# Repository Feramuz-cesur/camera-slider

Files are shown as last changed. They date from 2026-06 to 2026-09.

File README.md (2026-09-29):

# Camera Slider

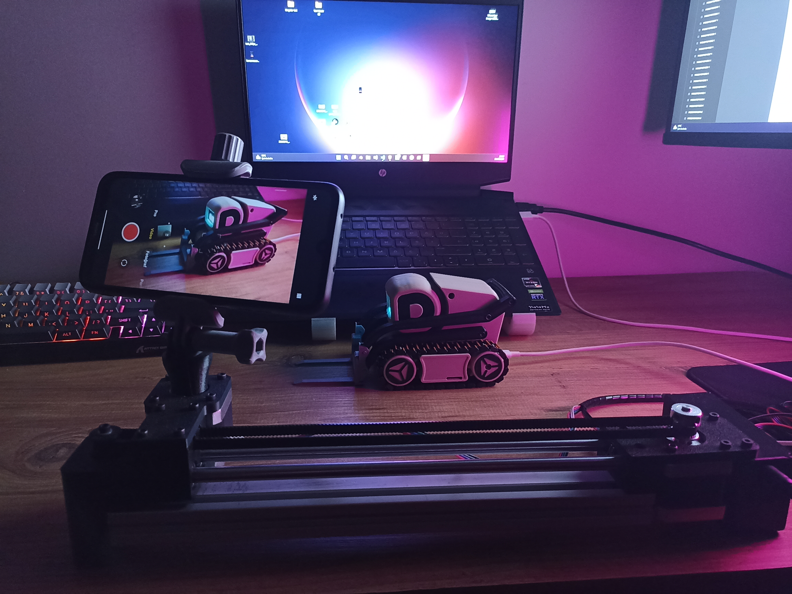
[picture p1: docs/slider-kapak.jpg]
Camera Slider: telefonla çekim yaparken


ESP32-C3 tabanlı, WiFi üzerinden kontrol edilen 2 eksenli motorlu kamera slider'ı.
Lineer eksen kamerayı GT2 kayışlı bir ray üzerinde taşır, rotary (pan) eksen ise
ray üzerindeki platformu 360° döndürür. Tüm kontrol telefon/bilgisayar
tarayıcısından çalışan web arayüzüyle yapılır — uygulama kurmak gerekmez.

## Özellikler

- **2 eksen:** lineer slider (NEMA 17 + GT2 kayış) ve 360° pan platformu (NEMA 17 direkt tahrik)
- **Web arayüzü:** cihaz üzerindeki LittleFS'ten sunulur; canlı durum ve kontrol WebSocket üzerinden
- **WiFi:** ev ağına bağlanır (`camera-slider.local`), bağlanamazsa kendi hotspot'unu açar
  (SSID `CameraSlider`, captive portal ile kurulum sayfası otomatik açılır)
- **Otomatik hareket:** başlangıç/bitiş noktaları arasında ayarlanabilir hızda gidiş-geliş,
  iki eksen ortak saat üzerinden senkron çalışır
- **Homing:** limit switch ile lineer eksen sıfırlama (hızlı yaklaş → geri çekil → yavaş tekrar yaklaş)
- **Jog:** web arayüzünden elle sürme, hız ayarlanabilir
- **OLED:** kart üzerindeki 0.42" ekranda IP adresi; açılışta Wi-Fi deneme sayacı,
  hotspot modunda ağ adı ve şifre
- Adım üretimi [FastAccelStepper](https://github.com/gin66/FastAccelStepper) ile donanım destekli

## İlk kullanım

1. Cihaza güç verin. Kayıtlı bir ağ yoksa **`CameraSlider`** isimli hotspot'u açar
   (şifre `12345678`).
2. Telefonunuzla bu ağa bağlanın. Kurulum sayfası kendiliğinden açılır; açılmazsa
   tarayıcıya elle **`http://192.168.4.1`** yazın (başındaki `http://` önemli).
3. Listeden ev ağınızı seçip şifresini girin. Cihaz yeniden bağlanır.
4. Bundan sonra kontrol arayüzüne **`http://camera-slider.local`** adresinden
   ulaşırsınız — IP adresi kart üzerindeki OLED ekranda da yazar.

## Arayüz

Arayüz

## PrintLapse ile 3D Yazıcı Timelapse Videoları Oluşturma

Slider, **[PrintLapse](https://play.google.com/store/apps/details?id=com.printlapse)**
Android uygulamasıyla birlikte 3D baskıların timelapse videosunu çekmek için
kullanılabilir. Her katmanda bir fotoğraf çekilir ve kamera, baskı boyunca
başlangıç noktasından bitiş noktasına doğru yavaşça ilerleyerek videoya hareket katar.

📱 **Uygulamayı indirin:** [PrintLapse — Google Play](https://play.google.com/store/apps/details?id=com.printlapse)

PrintLapse ile kullanımda akış görseldeki gibidir:

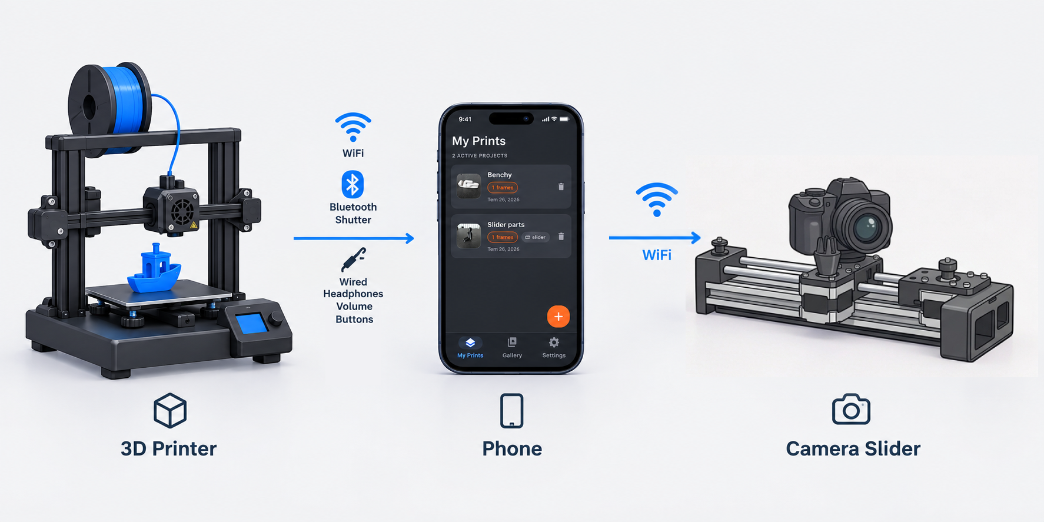
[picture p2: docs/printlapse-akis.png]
PrintLapse ile kullanım akışı: 3D yazıcı, telefon ve Camera Slider


1. **Yazıcı → telefon:** Yazıcı her katman değişiminde telefona bir tetik gönderir.
2. **Telefon:** PrintLapse tetiği alır ve bir fotoğraf çeker.
3. **Telefon → slider:** Fotoğraf çekildikten sonra PrintLapse, Wi-Fi üzerinden
   slider'a bir sonraki katman numarasını gönderir. Slider her iki ekseni o katmana
   karşılık gelen konuma götürür. Fotoğraf çekilirken slider hareket etmez.

Konumlar başlangıç ve bitiş arasında eşit aralıklarla dağıtılır: ilk katman
başlangıç noktasına, son katman bitiş noktasına denk gelir.

### Tetikleyici seçenekleri

Her katman değişiminde yazıcı kafayı sabit bir park noktasına götürür ve
fotoğrafı iki yoldan biriyle tetikler:

| Tetikleyici | Nasıl çalışır |
|---|---|
| **Wi-Fi** | Yazıcı telefona `http://<telefonun-IP-adresi>:5000/foto-cek` isteği gönderir. Uygulamada **Ayarlar → Ağ Tetikleyici** açık olmalıdır. |
| **Switch (deklanşör)** | Kafa, park noktasından biraz daha sağa giderek yazıcıya sabitlenmiş bir switch'e dokunur. Switch'in uçlarına bir **Bluetooth deklanşörün** ya da **kablolu kulaklığın ses tuşunun** kontakları lehimlenir; telefon bunu ses tuşuna basılmış gibi algılar. Ağ bağlantısı gerektirmez. Switch kutusunun baskı dosyaları [`3d-models/shutter/`](3d-models/shutter/) klasöründedir. |

Switch kutusunun yazıcıya takılmış hâlini ve içindeki bağlantıları gösteren
fotoğraflar da aynı klasördedir:
[üstten](3d-models/shutter/kurulum-ustten.jpg) ·
[yandan](3d-models/shutter/kurulum-yandan.jpg) ·
[parçalar ve kablolama](3d-models/shutter/parcalar.jpg).

> **Not:** Switch kutusu **Artillery Sidewinder X4 Pro** için tasarlandı; başka
> yazıcılara oturmayabilir. Kendi yazıcınız için internette benzer bir
> switch/deklanşör tutucusu aratabilirsiniz.

### Klipper makrosu

Aşağıdaki makrolar `printer.cfg` dosyasına eklenir. Wi-Fi ile tetikleme için
Klipper'da **G-Code Shell Command** eklentisi kurulu olmalıdır
([KIAUH](https://github.com/dw-0/kiauh) → Extensions menüsünden kurulabilir).

```ini
[gcode_macro TIMELAPSE_ON]
description: Timelapse aktif
gcode:
  SET_GCODE_VARIABLE MACRO=TIMELAPSE VARIABLE=enabled VALUE=1
  M117 Timelapse ACIK

[gcode_macro TIMELAPSE_OFF]
description: Timelapse kapat
gcode:
  SET_GCODE_VARIABLE MACRO=TIMELAPSE VARIABLE=enabled VALUE=0
  M117 Timelapse KAPALI

[gcode_macro TIMELAPSE]
variable_enabled: 0
gcode:
  {% if enabled == 1 %}
    {% set retract = params.E | default(1.5) | float %}
    {% set z_hop = params.Z | default(1) | float %}
    {% set park_x = params.X | default(239) | float %}
    {% set park_y = params.Y | default(240) | float %}

    G91
    G1 E-{retract} F2100            ; filamenti geri çek
    G1 Z{z_hop} F600                ; nozzle'ı baskıdan kaldır
    G90
    G1 X{park_x} Y{park_y} F7000    ; park noktasına git
    M400
    G4 P300                         ; titreşim dinsin
    RUN_SHELL_COMMAND CMD=tetikle_kamera
    G4 P1500                        ; fotoğraf çekilsin
    G91
    G1 Z-{z_hop} F600
    M83
    G1 E{retract} F2100
    G90
  {% endif %}

[gcode_shell_command tetikle_kamera]
command: curl http://<TELEFONUN_IP_ADRESI>:5000/foto-cek
timeout: 6.
verbose: False
```

**Switch ile tetiklemek için** makrodaki `RUN_SHELL_COMMAND CMD=tetikle_kamera`
satırının yerine kafayı switch'e götürüp geri çeken hareketi yazın. Mesafe,
switch'in nereye takıldığına göre yazıcıdan yazıcıya değişir:

```ini
    G1 X{park_x + 8} F3000          ; switch'e dokun (mesafeyi yazıcınıza göre ayarlayın)
    G4 P200
    G1 X{park_x} F3000              ; geri çekil
```

Kullanmadan önce:

- Dilimleyicinizde (slicer) her katman değişiminde çalışan G-code alanına `TIMELAPSE`
  satırını ekleyin. OrcaSlicer'da bu alan **Printer settings → Machine G-code →
  Timelapse G-code** altındadır:

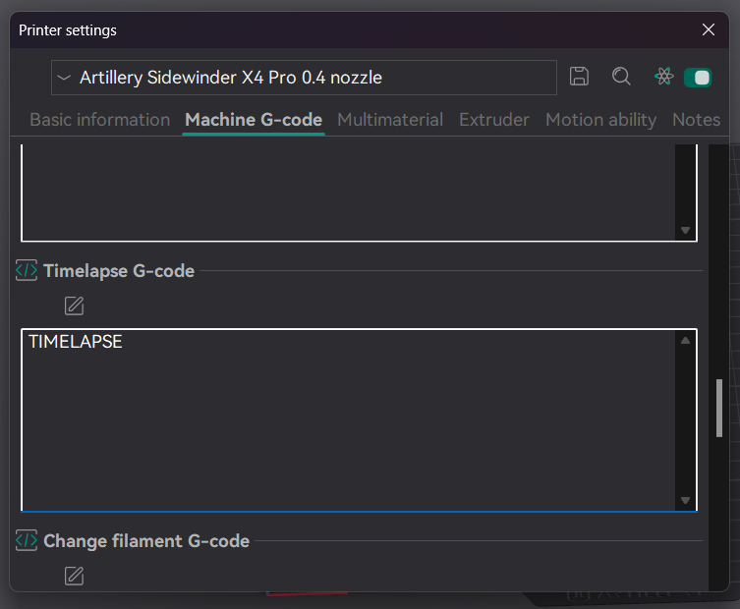
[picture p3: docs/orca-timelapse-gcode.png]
OrcaSlicer'da Timelapse G-code alanına TIMELAPSE yazılması
  

- Makro varsayılan olarak kapalıdır: baskıdan önce `TIMELAPSE_ON` çalıştırın
  (ya da `PRINT_START` makronuza ekleyin).
- Park noktasını yazıcınıza göre değiştirebilirsiniz: `TIMELAPSE X=230 Y=230`.

### PrintLapse kullanımı

1. **Slider'ı hazırlayın.** Web arayüzünde sıfırlama (homing) adımlarını tamamlayın,
   slider'ı istediğiniz konumlara sürüp **Use as Start** ve **Use as End**
   butonlarıyla başlangıç ve bitiş noktalarını kaydedin.
2. **Slider'ın adresini girin.** PrintLapse'te **Ayarlar → Kızak IP Adresi** alanına
   slider'ın OLED ekranında yazan IP adresini yazın ve **Bağlantıyı Test Et**'e basın.
   Telefon ve slider aynı Wi-Fi ağında olmalıdır.
3. **Tetikleyiciyi hazırlayın.** Yazıcıya [Klipper makrosunu](#klipper-makrosu)
   ekleyin. Wi-Fi ile tetikleyecekseniz uygulamada **Ayarlar → Ağ Tetikleyici**
   seçeneğini açın.
4. **Projeyi oluşturun.** Yeni bir proje açın, **Kamera kızağını kullan** seçeneğini
   açın ve **Toplam Katman** alanına dilimleyicide (slicer) görünen katman sayısını
   yazın. Ardından **Kamerayı Başlat**'a basın.
5. **Kontrol edin.** Kamera ekranının üstündeki **KIZAK** kartında bağlantı durumu,
   slider'ın konumu ve çekilen kare sayısı görünür. **Başa Git** slider'ı başlangıç
   noktasına götürür; **Önizleme** ise başlangıçtan bitişe bir deneme turu attırır.
   Kartta turuncu bir uyarı varsa (ör. "Sıfırlama gerekli", "Başlangıç ve bitiş
   ayarlanmamış") önce onu giderin.
6. **Baskıyı başlatın.** Her tetikte bir kare çekilir ve slider bir sonraki konuma
   geçer. Toplam katman sayısına ulaşıldığında uygulama sizi bilgilendirir.

Bağlantı sorunları yaşarsanız [Sorun giderme](#sorun-giderme) bölümüne bakın.

## Donanım

| Parça | Açıklama |
|---|---|
| ESP32-C3 0.42" OLED SuperMini | Ana kontrolcü (dahili SSD1306 72×40 OLED) |
| 2× A4988 | Step motor sürücüleri (1/16 mikro adım) |
| 2× NEMA 17 | 1.8°/adım; biri lineer eksen, biri pan |
| AMS1117 5V regülatör modülü | 12V → 5V (ESP32 beslemesi) |
| Lever limit switch (JL012-13.5-2) | Lineer eksen sıfır noktası |
| 12V adaptör + barrel jack | Motor beslemesi |

### Mekanik / bağlantı malzemeleri

| Parça | Adet | Not |
|---|---|---|
| 20 × 40 mm sigma profil, 300 mm | 1 | Slider gövdesi |
| 8 mm çap, 300 mm lineer mil | 2 | Araba kızağı |
| LM8UU lineer rulman | 2 | 8 mm mil için |
| M3 × 10 mm cıvata | 17 | Genel montaj |
| M3 × 25 mm cıvata | 2 | — |
| M3 somun | 4 | — |
| M3 insert somun (ısıyla gömme) | 7 | 3D baskı parçalara gömülür |
| M5 × 25 mm cıvata | 1 | Telefon tutucu bağlantısı |
| M5 somun | 1 | Telefon tutucu bağlantısı |
| 30 × 70 mm delikli pertinaks | 1 | Sürücü/kablo bağlantı kartı |

## Bağlantı şeması

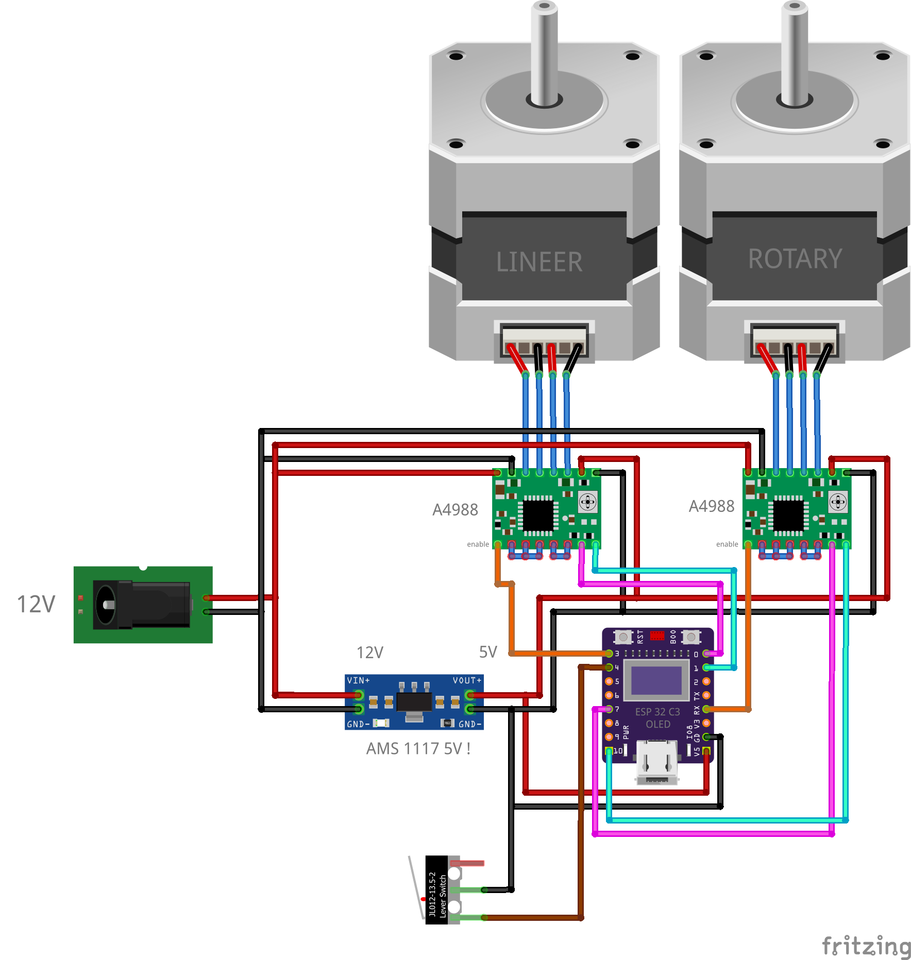
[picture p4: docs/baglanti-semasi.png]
Bağlantı şeması


Yüksek çözünürlüklü PDF: [docs/baglanti-semasi.pdf](docs/baglanti-semasi.pdf)

### Pin haritası

| ESP32-C3 pini | Nereye gidiyor | Not |
|---|---|---|
| GPIO0 | A4988 #1 — STEP | Lineer eksen adım sinyali |
| GPIO1 | A4988 #1 — DIR | Lineer eksen yön |
| GPIO3 | A4988 #1 — ENABLE | Aktif LOW (LOW = sürücü etkin) |
| GPIO4 | Limit switch → GND | `INPUT_PULLUP`; basılınca LOW |
| GPIO7 | A4988 #2 — STEP | Pan ekseni adım sinyali |
| GPIO10 | A4988 #2 — DIR | Pan ekseni yön |
| GPIO20 | A4988 #2 — ENABLE | UART0-TX pini; Serial USB-CDC'de olduğundan serbest |
| GPIO21 | Pan limit switch (rezerve) | Bağlı değil, `PAN_HAS_LIMIT=0` |
| GPIO5 / GPIO6 | Dahili OLED SDA / SCL | Kart üzerinde sabit; I²C `0x3C` |
| 5V | AMS1117 çıkışı | ESP32 beslemesi (USB takılıyken gerekmez) |
| 3V3 | Her iki A4988 — VDD | Sürücü lojik beslemesi |
| GND | Ortak toprak | ESP + sürücüler + 12V kaynak + limit switch |

**A4988 kurulumu:** RESET ↔ SLEEP köprülü; MS1 = MS2 = MS3 = HIGH → 1/16 mikro adım
(koddaki `DRIVER_MICROSTEP 16` ile eşleşmeli); her sürücünün VMOT–GND arasına
100 µF kondansatör. Akım limiti Vref potuyla ayarlanır.

**Kaçınılacak pinler:** GPIO2, GPIO8, GPIO9 (strapping/BOOT), GPIO18/19 (USB D−/D+), GPIO11–17 (flash).

## Montaj bilgileri

Slider montajı: parçaların patlatılmış görünümü

png 1

png 2

### 3D baskı parçaları

Basılması gereken tüm parçaların STL dosyaları [`3d-models/`](3d-models/)
klasöründe:

```
3d-models/
├── slider/           Projeye özel parçalar (motor yatakları, araba, kayış tutucu vb.)
├── shutter/          Yazıcı kafasının bastığı switch kutusu (PrintLapse tetikleyicisi)
└── telefon-tutucu/   Telefon tutucu modülleri (harici tasarım — aşağıya bakın)
```

Önerilen baskı ayarları ve parça listesi için [`3d-models/README.md`](3d-models/README.md)
dosyasına bakın.

#### Telefon tutucu — atıf

`3d-models/telefon-tutucu/` içindeki modeller bana ait değil:
[HeyVye](https://www.thingiverse.com/thing:2194278) tarafından tasarlanan
**Modular Mounting System** projesinden, Creative Commons Attribution (CC BY)
lisansıyla. Kullanıcı ayrıca aramak zorunda kalmasın diye repoya ekledim.
Bu kısmın montajı için orijinal sayfadaki talimatları izleyin — modüller M5
cıvata/somun ile birleşir, bağlantı noktası GoPro uyumludur.

## Mekanik / kalibrasyon varsayılanları

- Lineer: 200 adım/tur × 16 mikro adım = 3200 adım/tur; GT2 20T kasnak (40 mm/tur) → **80 adım/mm**
- Pan: direkt tahrik, 3200 adım = 360°
- Maks. yol 300 mm, maks. hız 50 mm/s — hepsi web arayüzünden değiştirilebilir ve kalıcı saklanır

## Derleme ve yükleme

Proje [PlatformIO](https://platformio.org/) ile derlenir:

```
pio run -t upload          # firmware
pio run -t uploadfs        # web arayüzü (data/ → LittleFS)
```

İkisini de yükledikten sonra cihaz açılışta hotspot'unu açar — devamı için
[İlk kullanım](#ilk-kullanım) bölümüne bakın.

## Sorun giderme

### Slider beklendiği gibi çalışmıyorsa: önce Wi-Fi mesafesine bakın

Uygulamada sık sık **"Bağlı değil"** görmek, komutların gecikmesi, kareler arasında
slider'ın hareket etmemesi ya da açılışta ev ağına bağlanamayıp hotspot moduna
düşmesi gibi sorunların büyük çoğunluğunun sebebi **slider'ın modemden uzakta
olmasıdır.**

ESP32-C3 SuperMini kartı, kartın üzerine lehimli küçük bir **SMD (seramik) anten**
kullanır. Harici anten konnektörlü ya da daha büyük PCB antenli ESP32 modellerine
göre hem yayın hem de alış gücü belirgin şekilde düşüktür. Telefonunuzun aynı
noktada rahatça bağlandığı bir ağ, slider için sınırda olabilir.

Yapabilecekleriniz (etkisi büyükten küçüğe):

- **Slider'ı modeme yaklaştırın** ya da aradaki duvar sayısını azaltın. Mümkünse
  modemle aynı odada kullanın; olmuyorsa araya bir Wi-Fi genişletici / mesh noktası koyun.
- **Antenin etrafını boş bırakın.** Antenin 1–1,5 cm çevresinde metal olmasın:
  alüminyum profil, motor kabloları ve kablo demeti anteni "söndürür" (20 dB kayıp
  sıradandır). Kutu içinde antenin metal parçalara değil, plastik duvara bakmasını sağlayın.
- **Motor kablolarını** ikişerli burgu yapın ve antenden uzak geçirin.
- **Beslemeyi güçlendirin.** Wi-Fi yayını sırasında kart anlık olarak yüksek akım
  çeker; 3,3 V hattı çökerse sinyal bozulur. ESP kartının hemen yanına
  470–1000 µF + 100 nF kondansatör koyun, her A4988'in VMOT girişine yakın 100 µF
  ekleyin ve motor topraklamasının ESP'nin toprağı üzerinden dönmemesine dikkat edin.

**Sinyal gücünü ölçmek için** kartı USB ile bilgisayara bağlayıp seri monitörü açın
(`pio device monitor`, 115200 baud). Kart ağa bağlandığında şöyle bir satır yazar:

```
[wifi] connected to EvAgim  RSSI -58 dBm  IP 192.168.1.110
```

| RSSI | Anlamı |
|---|---|
| -30 … -60 dBm | İyi |
| -60 … -70 dBm | Kullanılabilir, ara sıra kopma olabilir |
| -70 dBm'den kötü | Zayıf — kopmalar ve açılışta bağlanamama beklenir |

Zayıf sinyalde seri monitörde `[wifi] attempt 2 failed: AUTH_FAIL` ya da
`[wifi] link lost` satırları da görülür. Şifre doğru olsa bile ESP32 zayıf
sinyalde `AUTH_FAIL` bildirebilir.

### Açılışta ev ağına bağlanamıyor

- Açılışta OLED'de **"Connecting"** ve altında büyük bir **deneme sayısı** görünür.
  Kart, kayıtlı ağa yaklaşık 22 saniye boyunca tekrar tekrar bağlanmayı dener.
- Bağlanamazsa hotspot moduna geçer ve OLED'de **"AP MODE"**, ağ adı (`CameraSlider`)
  ve şifre (`12345678`) yazar.
- Hotspot'a kimse bağlı değilken kart, dakikada bir ev ağını sessizce tekrar dener.
  Modem geç açıldıysa ya da ilk deneme şanssız geçtiyse **reset'e basmadan**
  kendiliğinden bağlanır.
- Her seferinde "AP MODE"a düşüyorsa ya şifre yanlıştır (hotspot'a bağlanıp tekrar
  girin) ya da sinyal zayıftır (yukarıdaki bölüm).

### Kurulum sayfası kendiliğinden açılmıyor

- Tarayıcıya elle **`http://192.168.4.1`** yazın (başındaki `http://` önemli).
- Bazı telefonlar, internet erişimi olmayan bu ağı "internet yok" diye bırakıp mobil
  veriye döner. Telefonun sorduğu "bu ağda kal / bağlı kal" seçeneğini onaylayın ya
  da kurulum süresince mobil veriyi kapatın.

### Uygulamada "Başlangıç ve bitiş ayarlanmamış" yazıyor

Slider'a hiç başlangıç/bitiş noktası kaydedilmemiş demektir. Web arayüzünde
slider'ı istediğiniz konuma sürüp **Use as Start** ve **Use as End** butonlarına
basın. Kaydedilmemiş olan buton turuncu görünür. Firmware güncellemesinden önce
açılmış bir tarayıcı sekmesi kullanıyorsanız önce sayfayı yenileyin.

## Proje yapısı

```
src/            Firmware kaynak kodu (Config.h: tüm pin ve varsayılan ayarlar)
data/           Web arayüzü (LittleFS'e yüklenir)
docs/           Bağlantı şeması (PNG + PDF, Fritzing çizimi)
3d-models/      Basılacak parçaların STL dosyaları
platformio.ini  Derleme yapılandırması
```

## Lisans

Bu projenin kaynak kodu ve tasarım dosyaları MIT lisansı altındadır — bkz.
[LICENSE](LICENSE). `3d-models/telefon-tutucu/` klasörü istisnadır; o parçalar
üçüncü tarafa ait olup CC BY lisansıyla dağıtılır (yukarıdaki atfa bakın).

## Teşekkür

- Telefon tutucu modülleri: **Modular Mounting System** — [HeyVye](https://www.thingiverse.com/thing:2194278) (CC BY)
- Adım üretimi: [FastAccelStepper](https://github.com/gin66/FastAccelStepper) — gin66

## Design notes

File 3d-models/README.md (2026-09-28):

# 3D Modeller

Camera Slider'ın basılması gereken parçalarının STL dosyaları.

```
3d-models/
├── slider/           Projeye özel parçalar (kendi tasarımım)
├── shutter/          PrintLapse için switch kutusu, top + bottom + kurulum fotoğrafları
│                     (kendi tasarımım, Artillery Sidewinder X4 Pro için)
└── telefon-tutucu/   HeyVye'nin Modular Mounting System parçaları (bkz. aşağıdaki not)
```

## Baskı önerileri

| Ayar | Değer |
|---|---|
| Malzeme | PLA / PETG |
| Katman yüksekliği | 0.2 mm |
| Duvar sayısı | 3–4 |
| Doluluk | %30–40 (motor ve kayış tutan parçalarda %50) |
| Destek | Yalnızca gerektiren parçalarda |

## Telefon tutucu — atıf

`telefon-tutucu/` klasöründeki modeller **bana ait değildir**. Bu parçalar
[HeyVye](https://www.thingiverse.com/thing:2194278) tarafından tasarlanan
**Modular Mounting System** projesine aittir ve Creative Commons — Attribution
(CC BY) lisansı ile yayınlanmıştır.

Bu dosyalar projede yalnızca **destekleyici bir eleman** olarak kullanılmıştır;
kullanıcının parçaları tek tek aramasına gerek kalmasın diye orijinal
kaynaktan indirilip buraya kopyalanmıştır. Tasarımın tüm hakları ve emeği
orijinal tasarımcıya aittir.

**Bu parçaların montajı için orijinal tasarımcının sayfasındaki talimatları
izleyin:** https://www.thingiverse.com/thing:2194278

Modüller M5 cıvata/somun kullanır ve GoPro uyumlu bağlantıya sahiptir.

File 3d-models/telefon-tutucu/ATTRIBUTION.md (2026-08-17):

# Telefon tutucu — orijinal tasarımcıya ait

Bu klasördeki STL dosyaları **Camera Slider projesine ait değildir** ve
tarafımdan tasarlanmamıştır.

- **Tasarım:** Modular Mounting System
- **Tasarımcı:** HeyVye
- **Kaynak:** https://www.thingiverse.com/thing:2194278
- **Lisans:** Creative Commons — Attribution (CC BY)

Dosyalar burada yalnızca kullanıcı kolaylığı için bulunuyor; slider'a kamera
yerine telefon takmak isteyenler için destekleyici bir parça olarak
kullanılmıştır.

**Montaj:** Bu parçaların nasıl birleştirileceği için orijinal tasarımcının
yukarıdaki sayfadaki açıklama ve talimatlarını uygulayın. Modüller M5
cıvata/somun ile birleşir ve bağlantı noktası GoPro uyumludur.

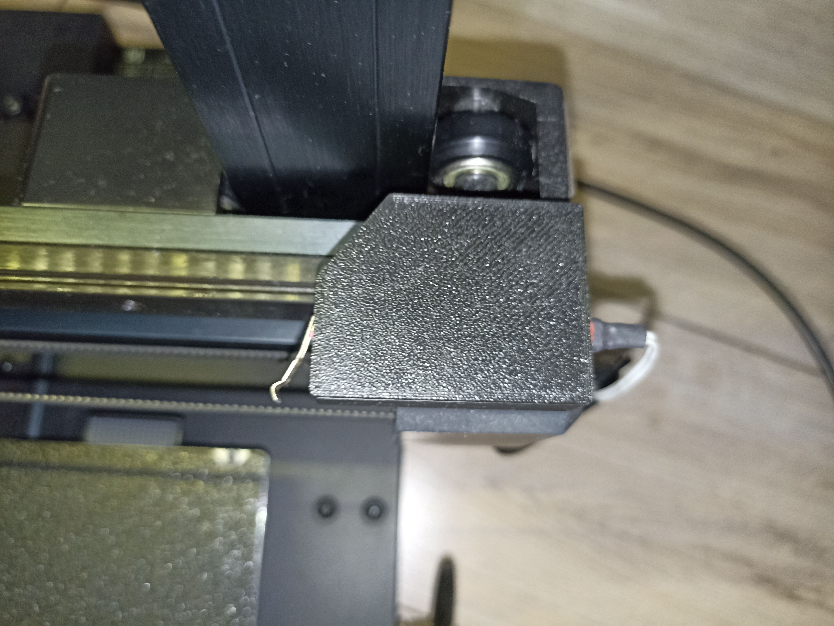
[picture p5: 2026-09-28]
3d-models/shutter/kurulum-ustten.jpg

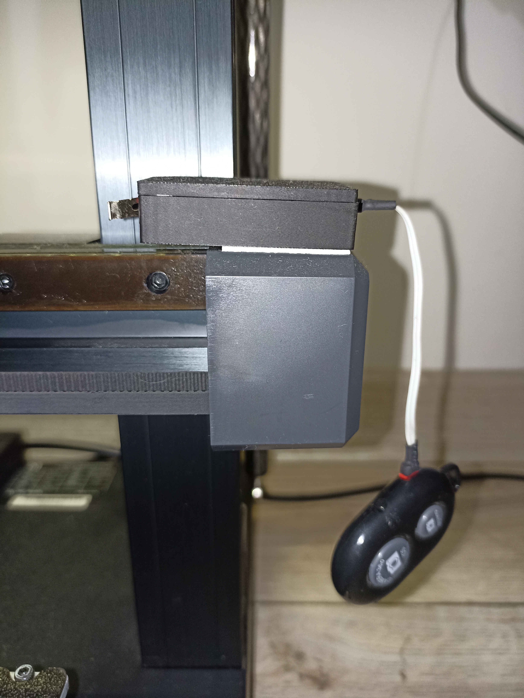
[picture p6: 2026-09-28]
3d-models/shutter/kurulum-yandan.jpg

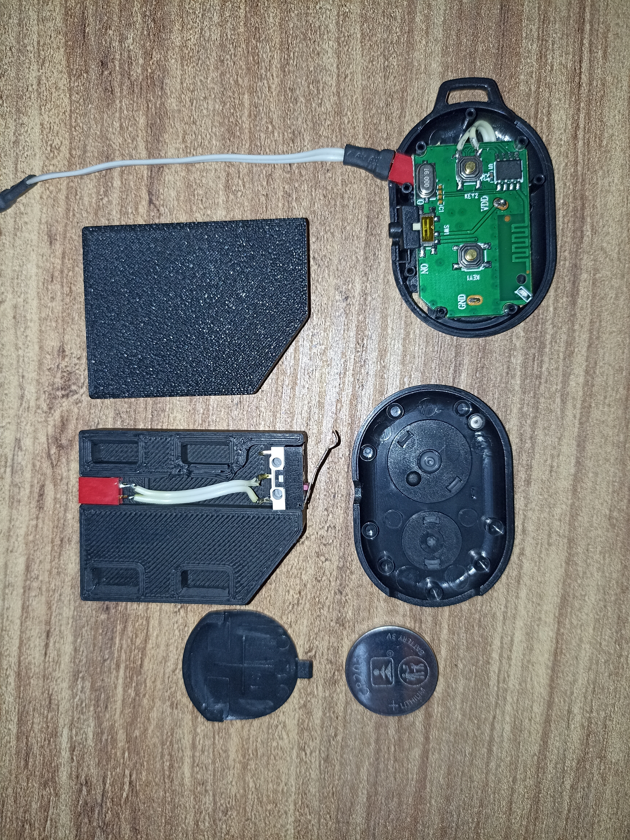
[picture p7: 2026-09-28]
3d-models/shutter/parcalar.jpg

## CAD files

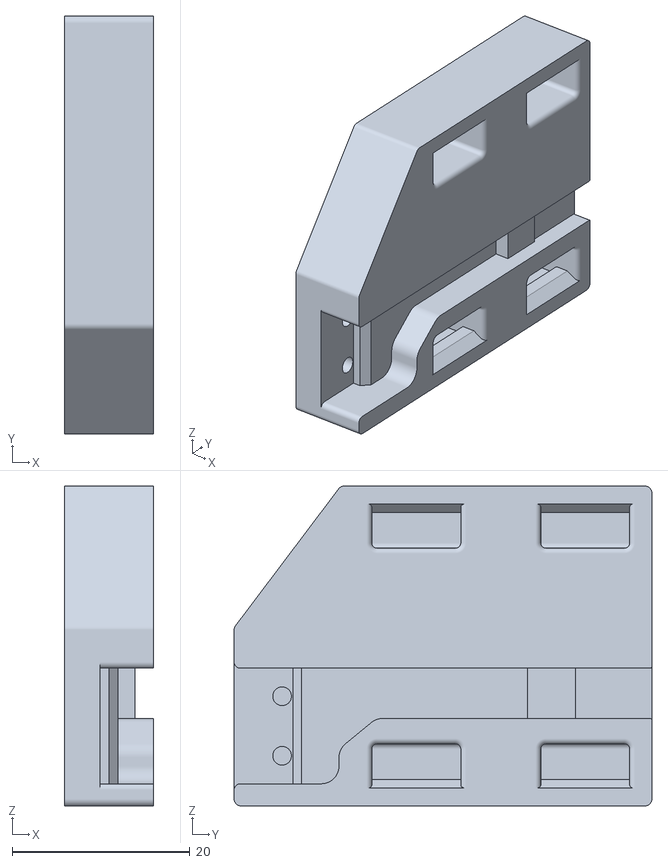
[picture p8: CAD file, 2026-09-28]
3d-models/shutter/bottom.STL
10.0 x 47.0 x 36.0

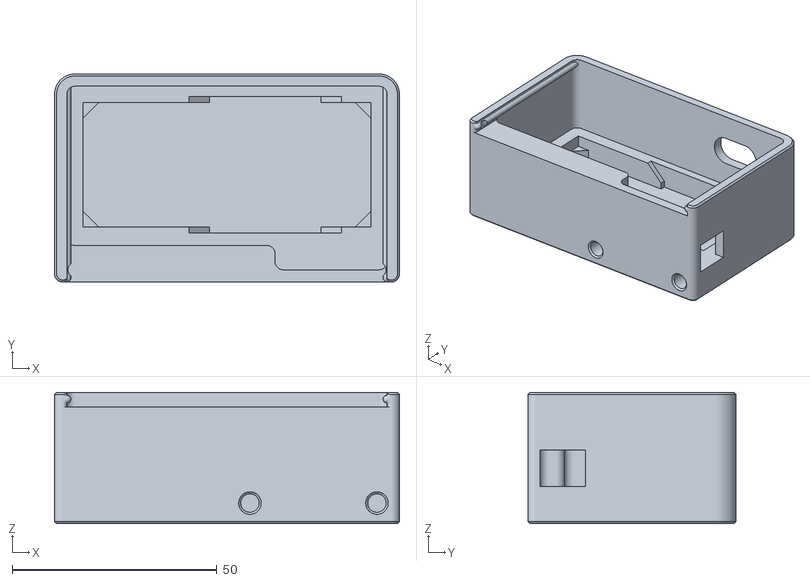
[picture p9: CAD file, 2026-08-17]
3d-models/slider/box body.stl
84.2 x 50.8 x 32.0

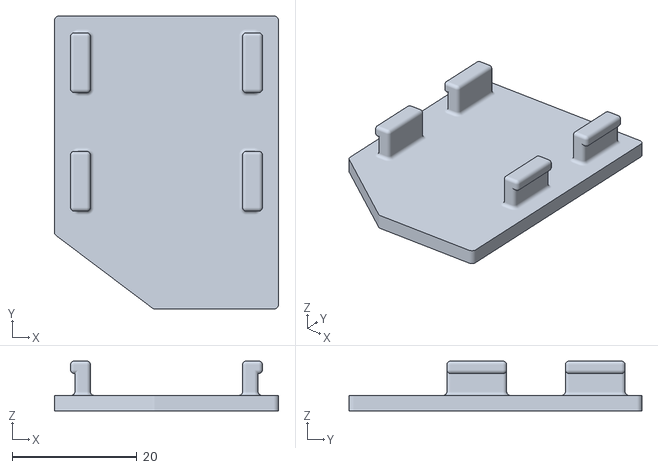
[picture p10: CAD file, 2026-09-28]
3d-models/shutter/top.STL
36.0 x 47.0 x 8.00

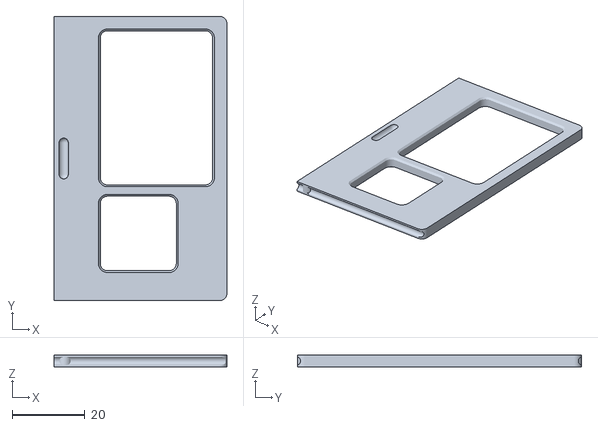
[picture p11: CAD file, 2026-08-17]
3d-models/slider/box lid.stl
47.4 x 77.9 x 3.30

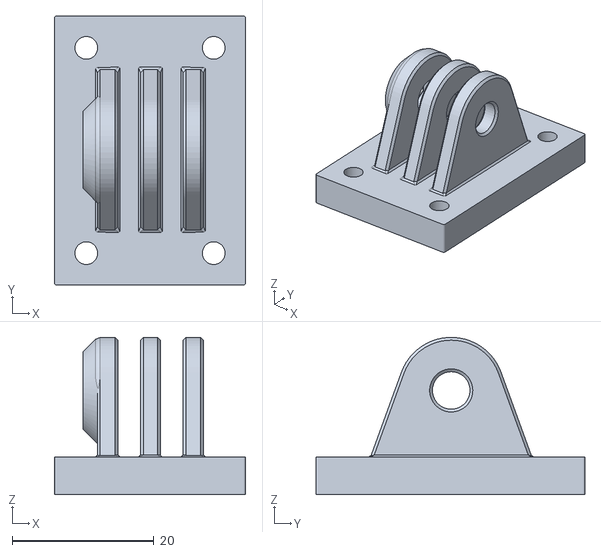
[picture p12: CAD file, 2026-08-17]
3d-models/slider/one axis.stl
27.0 x 38.0 x 22.2

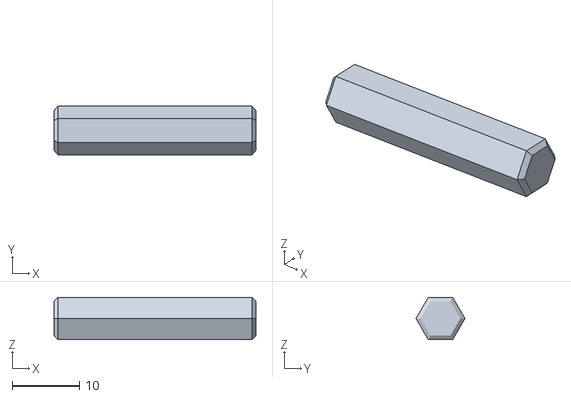
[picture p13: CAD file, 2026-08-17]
3d-models/telefon-tutucu/Hex Shaft 6.35.stl
30.0 x 7.27 x 6.30

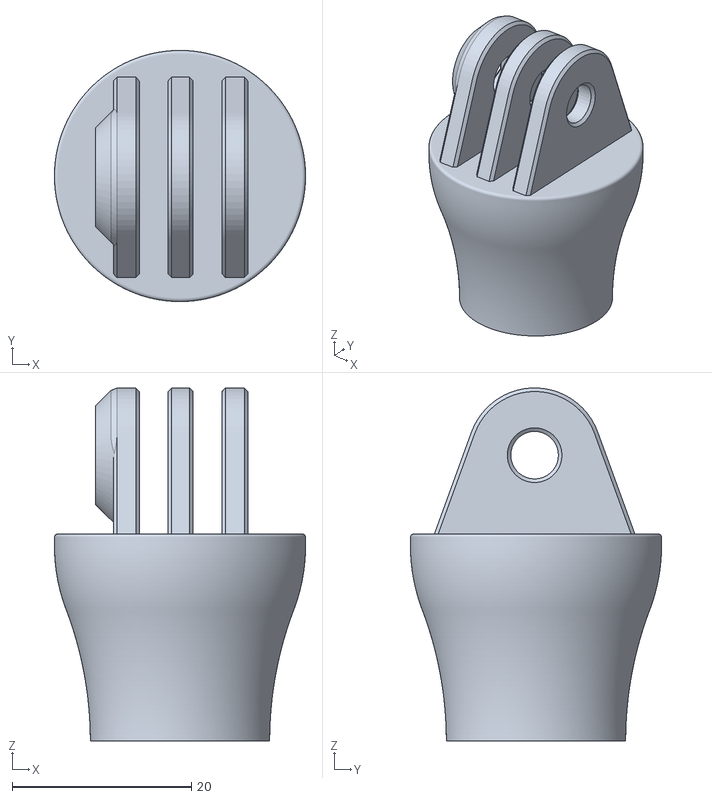
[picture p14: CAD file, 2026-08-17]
3d-models/slider/two axis.stl
28.0 x 28.0 x 39.4

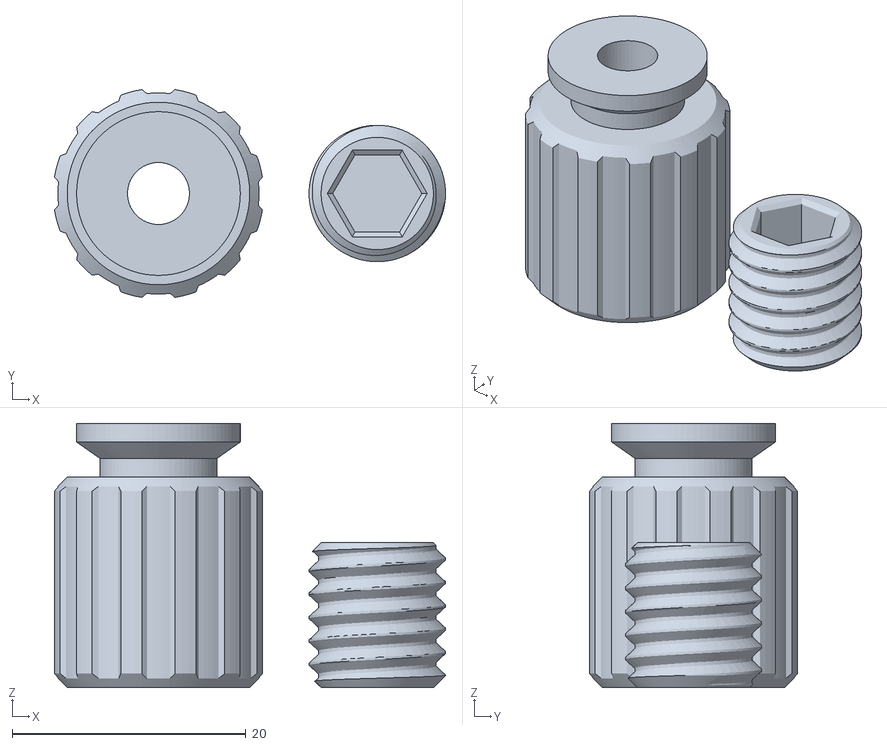
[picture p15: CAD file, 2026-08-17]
3d-models/telefon-tutucu/Mount Phone Clamp Knob.stl
33.4 x 17.8 x 22.6

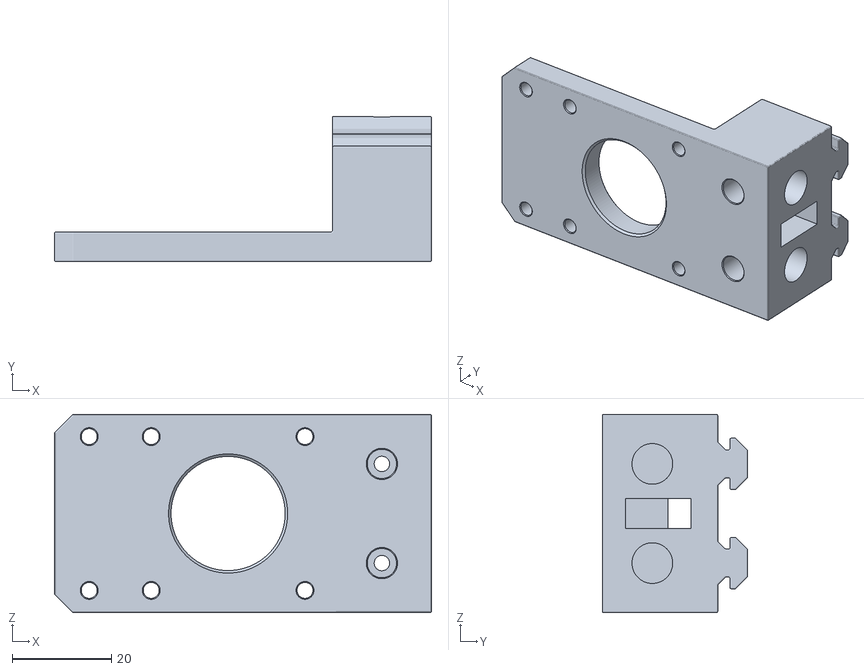
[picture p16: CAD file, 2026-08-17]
3d-models/slider/Part1.stl
76.0 x 29.3 x 40.0

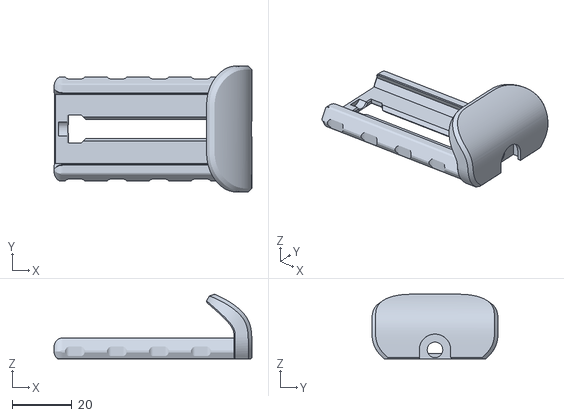
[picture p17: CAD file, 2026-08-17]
3d-models/telefon-tutucu/Mount Phone Clamp A v6.stl
66.0 x 42.0 x 21.6

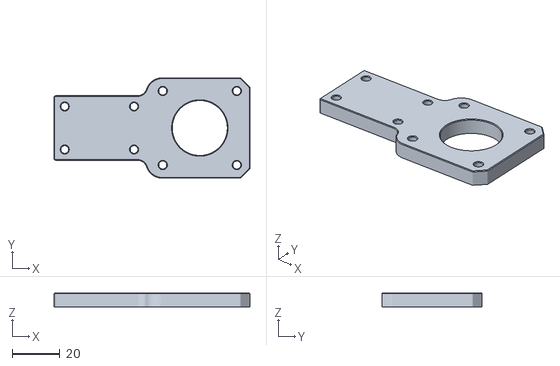
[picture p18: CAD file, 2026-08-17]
3d-models/slider/top part.stl
82.0 x 42.0 x 6.00

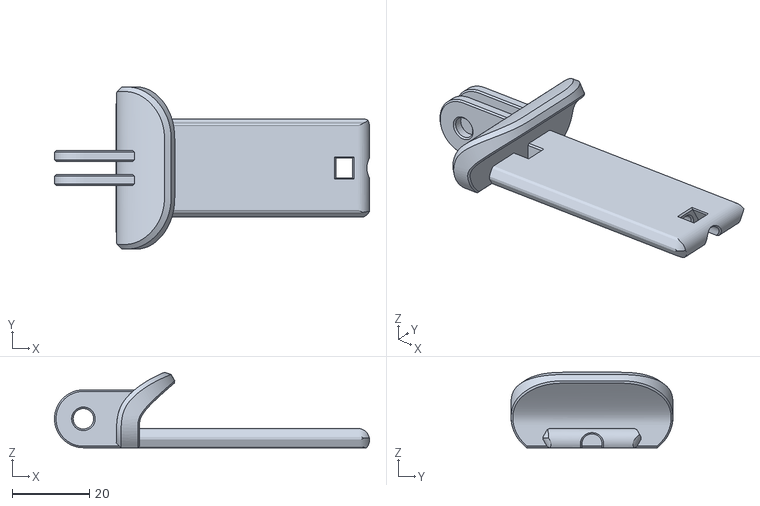
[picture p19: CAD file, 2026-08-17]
3d-models/telefon-tutucu/Mount Phone Clamp B with Tab v6.stl
81.5 x 42.0 x 19.6

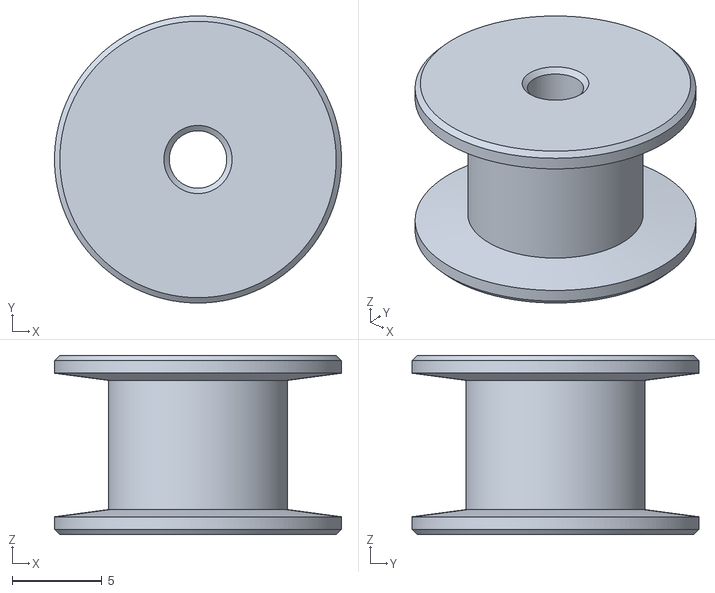
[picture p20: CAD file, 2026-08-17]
3d-models/slider/Gt2 holder.stl
16.0 x 16.0 x 10.0

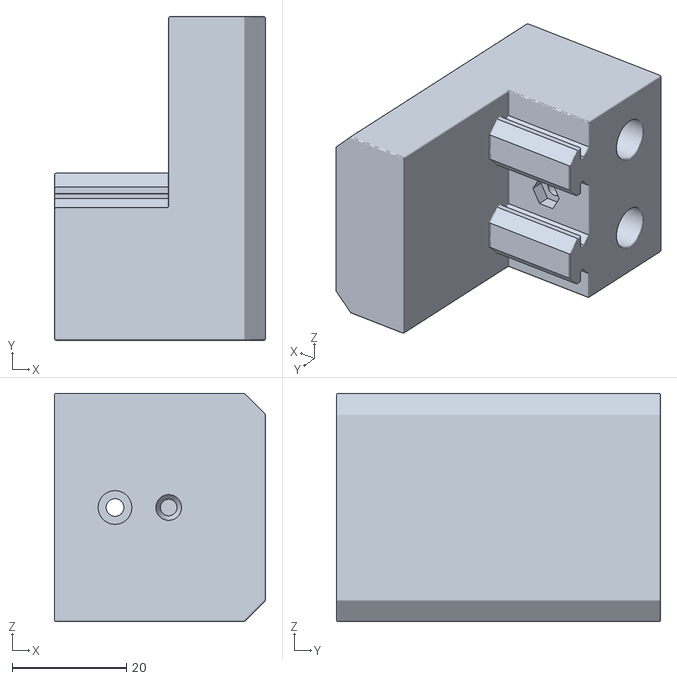
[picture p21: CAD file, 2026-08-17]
3d-models/slider/Part2.stl
37.0 x 56.8 x 40.0

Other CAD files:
3d-models/slider/spacer.stl
3d-models/slider/compression part.stl
3d-models/telefon-tutucu/Knob for nut long v1.stl
3d-models/telefon-tutucu/Mount Phone Clamp Bolt v1.stl

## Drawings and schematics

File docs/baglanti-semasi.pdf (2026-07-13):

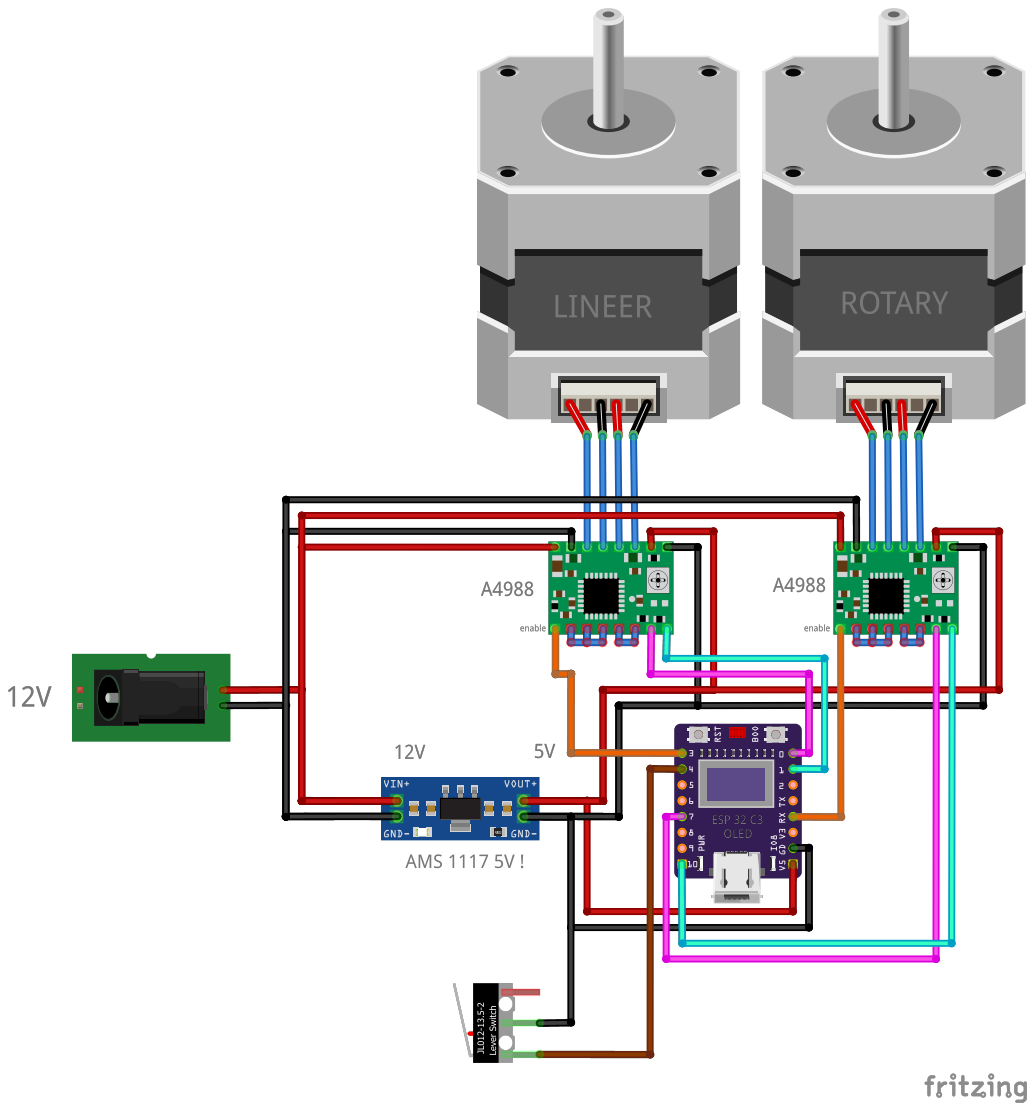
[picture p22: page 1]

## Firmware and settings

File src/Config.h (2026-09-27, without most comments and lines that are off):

#pragma once
#include <Arduino.h>
#define PIN_STEP        0   // GPIO0  -> A4988 #1 STEP
#define PIN_DIR         1   // GPIO1  -> A4988 #1 DIR
#define PIN_EN          3   // GPIO3  -> A4988 #1 ENABLE (active LOW)
#define PIN_LIMIT       4   // GPIO4  -> Slider limit switch (to GND when triggered)
#define PIN_STEP2       7   // GPIO7  -> A4988 #2 STEP
#define PIN_DIR2        10  // GPIO10 -> A4988 #2 DIR  (was ULN2003 IN4 on the old setup)
#define PIN_EN2         20  // GPIO20 -> A4988 #2 ENABLE (active LOW)
#define PIN_LIMIT2      21  // GPIO21 -> Pan limit switch (optional/reserved; INPUT_PULLUP)
#define PAN_HAS_LIMIT   0
#define PIN_OLED_SDA    5   // GPIO5
#define PIN_OLED_SCL    6   // GPIO6
#define HOMING_BACKOFF_STEPS    200     // back off after touching limit (~2.5 mm @ 80 steps/mm)
#define HOMING_SLOW_SPEED_S     400     // slow re-approach for accuracy (steps/s)
#define AP_SSID         "CameraSlider"
#define AP_PASSWORD     "12345678"     // min 8 chars
#define AP_CHANNEL      6
#define WIFI_TX_POWER   WIFI_POWER_8_5dBm
#define WIFI_STA_TX_POWER   WIFI_POWER_15dBm
#define WIFI_SCAN_DWELL_MS       150    // per-channel dwell -> 3 s deadline for that channel
#define WIFI_SCAN_CHANNEL_GAP_MS 250    // AP breathing room between channels
#define WIFI_SCAN_LAST_CHANNEL   13     // 2.4 GHz channels 1..13
#define WIFI_SCAN_MIN_PERIOD_MS  6000   // ignore refresh requests fired faster than this
#define WIFI_SCAN_MAX_RESULTS    30
#define WIFI_SCAN_CHANNEL_TIMEOUT_MS 2000
#define WIFI_DNS_BURST       8
#define WIFI_STA_TIMEOUT_MS     22500   // total budget, then fall back to AP (was 15000: +50%)
#define WIFI_STA_ATTEMPT_MS     6000    // restart an attempt that has not even associated by then
#define WIFI_STA_RETRY_GAP_MS   500     // let the driver settle between attempts
#define WIFI_STA_DHCP_GRACE_MS  4000    // associated as the budget ran out: let DHCP finish
#define WIFI_STA_WATCHDOG_MS    10000
#define WIFI_AP_RETRY_PERIOD_MS  60000  // AP idle this long -> try the saved network
#define WIFI_AP_RETRY_ATTEMPT_MS 8000   // give that try this long
#define MDNS_HOST            "camera-slider"   // reachable as camera-slider.local
#define DEVICE_NAME          "Fergineer Slider"  // user-visible device name
#define WIFI_CREDS_FILE      "/wifi.json"      // saved credentials on LittleFS
#define MOTOR_FULL_STEPS_PER_REV 200     // NEMA 17 = 1.8° per full step
#define DRIVER_MICROSTEP         16      // A4988 MS1/MS2/MS3 jumper setting (1,2,4,8,16)
#define DEFAULT_STEPS_PER_REV   (MOTOR_FULL_STEPS_PER_REV * DRIVER_MICROSTEP)  // 3200
#define DEFAULT_MM_PER_REV      40.0f    // GT2 20T pulley travel per turn
#define DEFAULT_MAX_TRAVEL_MM   300.0f
#define MAX_TRAVEL_LIMIT_MM     2000.0f
#define DEFAULT_MAX_SPEED_MMS   50.0f    // NEMA 17 + A4988 handles much higher rates
#define DEFAULT_ACCEL_MMS2      80.0f
#define DEFAULT_JOG_SPEED_MMS   30.0f    // manual jog speed (mm/s)
#define DEFAULT_HOMING_SPEED_MMS 10.0f   // approach speed toward the limit switch
#define DEFAULT_USE_ACCEL       false
#define DEFAULT_INVERT_DIR      false
#define DEFAULT_START_MM        0.0f
#define DEFAULT_END_MM          DEFAULT_MAX_TRAVEL_MM
#define DEFAULT_PAN_STEPS_PER_REV (MOTOR_FULL_STEPS_PER_REV * DRIVER_MICROSTEP)  // 3200
#define DEFAULT_PAN_MAX_DEG       360.0f   // usable rotation range
#define DEFAULT_PAN_MAX_SPEED_DEGS 90.0f   // deg/s upper limit
#define DEFAULT_PAN_ACCEL_DEGS2    180.0f  // deg/s^2
#define DEFAULT_PAN_JOG_SPEED_DEGS 45.0f   // manual jog speed (deg/s)
#define DEFAULT_PAN_INVERT_DIR     false
#define DEFAULT_PAN_HOME_DEG       180.0f
#define DEFAULT_PAN_START_DEG      0.0f
#define DEFAULT_PAN_END_DEG        360.0f
#define STATUS_UPDATE_MS        150
#define DISPLAY_UPDATE_MS       500     // OLED refresh period (only while motor idle)

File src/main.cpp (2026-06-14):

#include <Arduino.h>
#include "Config.h"
#include "Settings.h"
#include "SliderControl.h"
#include "SliderWifi.h"
#include "WebInterface.h"
#include "Display.h"

void setup() {
    Serial.begin(115200);   // ESP32-C3 native USB CDC

    Settings_begin();
    Display_begin();  // show splash while WiFi connects
    Slider_begin();
    Wifi_begin();     // STA (saved network) or AP fallback for provisioning
    Web_begin();

    Serial.printf("WiFi: %s  IP: %s\n", Wifi_ssid().c_str(), Wifi_ip().c_str());
}

void loop() {
    Slider_update();
    Web_loop();
    Wifi_loop();
    // Display now renders on its own FreeRTOS task (see Display_begin).
    yield();
}

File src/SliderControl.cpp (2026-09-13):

#include "SliderControl.h"
#include "Settings.h"
#include "Config.h"
#include <FastAccelStepper.h>

// Two A4988 step/direction drivers. Axis 0 = linear slider (mm), axis 1 = rotary
// pan (deg). Each driver has its own STEP/DIR/ENABLE; the ENABLE pins are active
// LOW. FastAccelStepper generates the STEP pulses from the ESP32-C3 RMT hardware
// (not from loop()), so step timing is immune to WiFi/web/OLED jitter — this is
// what removes the stutter the software stepper had. enableOutputs()/
// disableOutputs() energize or release the coils so resting motors/drivers stay
// cool. No run() call is needed; moveTo/move execute in the background.

struct Axis {
    FastAccelStepper* stepper;
    uint8_t      stepPin;
    uint8_t      dirPin;
    uint8_t      enPin;
    uint8_t      limitPin;
    bool         hasLimit;     // true when a homing switch is wired/used
    bool         energized;    // tracks enableOutputs/disableOutputs state
};

static FastAccelStepperEngine engine = FastAccelStepperEngine();

static Axis ax[AXIS_COUNT] = {
    { nullptr, PIN_STEP,  PIN_DIR,  PIN_EN,  PIN_LIMIT,  true,                false },
    { nullptr, PIN_STEP2, PIN_DIR2, PIN_EN2, PIN_LIMIT2, (bool)PAN_HAS_LIMIT, false },
};

static SliderState state = STATE_BOOT;
static bool        homed = false;              // linear axis referenced
static bool        panHomed = false;           // rotary zero accepted by the user
// Which axes currently have a hand-driven move (jog or goto) in flight. This is
// per axis, not a single "the" axis: the UI can only hold one jog button at a
// time, but a stop for one axis must never be swallowed because another axis
// was commanded after it - that used to leave the first motor running all the
// way to its target.
static bool        manualActive[AXIS_COUNT] = {false, false};
static bool        holdEnabled = true;         // keep coils energized while idle (holding torque)
// Per-axis release, on top of holdEnabled. The rotary homing step frees the pan
// coils so the platform can be turned to face forward by hand; everything else
// stays held. Cleared as soon as anything moves.
static bool        axisReleased[AXIS_COUNT] = {false, false};

// auto-move bookkeeping. Both axes are driven from one shared clock: every loop
// each axis is commanded to start + (end-start)*s, where s is the eased fraction
// of elapsed time. Neither axis can reach its end before the full duration, so
// they always finish together no matter how their distances/speeds differ.
static long     autoStartStep[AXIS_COUNT]  = {0, 0};
static long     autoTargetStep[AXIS_COUNT] = {0, 0};
static long     autoLastDesired[AXIS_COUNT]= {0, 0};  // last position commanded this run
static bool     autoMoving[AXIS_COUNT]     = {false, false};  // axis has a real move this run
static bool     autoEase[AXIS_COUNT]       = {true, true};    // smooth-step vs linear per axis
static uint32_t autoStartedMs      = 0;
static uint32_t autoDurationMs     = 0;
static uint32_t autoElapsedAtPause = 0;   // frozen elapsed time while paused

// ---------- Unit conversion ----------
static inline float stepsPerUnit(AxisId a) {
    // slider: steps per mm; pan: steps per degree
    return (a == AXIS_SLIDER) ? settings.stepsPerMm
                              : (settings.panStepsPerRev / 360.0f);
}
static inline long  unitToSteps(AxisId a, float u) { return (long)(u * stepsPerUnit(a) + (u < 0 ? -0.5f : 0.5f)); }
static inline float stepsToUnit(AxisId a, long s)  { return (float)s / stepsPerUnit(a); }

static inline float axisMaxSpeedUnits(AxisId a) {
    return (a == AXIS_SLIDER) ? settings.maxSpeedMmS : settings.panMaxSpeedDegS;
}
static inline float axisAccelUnits(AxisId a) {
    return (a == AXIS_SLIDER) ? settings.accelMmS2 : settings.panAccelDegS2;
}
static inline bool axisInvert(AxisId a) {
    return (a == AXIS_SLIDER) ? settings.invertDir : settings.panInvertDir;
}

// A deliberately huge acceleration used to make a move start/stop effectively
// instantly (e.g. jog response, or the linear axis with "smooth ramping" off).
static inline float instantAccelSteps(AxisId a) {
    return axisMaxSpeedUnits(a) * stepsPerUnit(a) * 50.0f;
}

// Map a 0..1 time fraction to a 0..1 motion fraction. Smooth-step eases in/out
// (gentle starts and stops for video); linear is constant velocity.
static inline float easeFrac(float f, bool smooth) {
    if (f <= 0.0f) return 0.0f;
    if (f >= 1.0f) return 1.0f;
    return smooth ? (f * f * (3.0f - 2.0f * f)) : f;
}
// Peak speed reached relative to the average. Smooth-step peaks at 1.5x average
// (at the midpoint); a linear ramp holds the average the whole way.
static inline float peakSpeedFactor(bool smooth) { return smooth ? 1.5f : 1.0f; }

float Slider_axisMax(AxisId a) {
    return (a == AXIS_SLIDER) ? settings.maxTravelMm : DEFAULT_PAN_MAX_DEG;
}

// ---------- FastAccelStepper helpers ----------
// Remaining steps to the commanded target (FastAccelStepper has no distanceToGo).
static inline long curStep(AxisId a) { return ax[a].stepper->getCurrentPosition(); }
static inline long tgtStep(AxisId a) { return ax[a].stepper->targetPos(); }
static inline long toGo(AxisId a)    { return tgtStep(a) - curStep(a); }

// Set speed/accel (in steps) for an axis. FastAccelStepper applies these on the
// next move/moveTo command.
static inline void setKinematics(AxisId a, float maxSpeedSteps, float accelSteps) {
    ax[a].stepper->setSpeedInHz((uint32_t)maxSpeedSteps);
    ax[a].stepper->setAcceleration((uint32_t)accelSteps);
}

// ---------- Power management ----------
static void axisPower(AxisId a, bool on) {
    if (!ax[a].stepper) return;
    if (on == ax[a].energized) return;
    if (on) ax[a].stepper->enableOutputs();
    else    ax[a].stepper->disableOutputs();
    ax[a].energized = on;
}

// Apply coil power for a given state. Motors are kept energized whenever
// holdEnabled is set, so they hold position even when idle and stay on after a
// move completes. Starting any motion re-arms the hold flag, so both the
// released-at-boot state and a one-shot "disable" last only until the next
// command. The user can release the coils on demand via
// Slider_setMotorsEnabled(false).
static void applyPowerFor(SliderState s) {
    bool moving = !(s == STATE_IDLE || s == STATE_BOOT || s == STATE_FAULT);
    if (moving) {
        holdEnabled = true;
        for (int i = 0; i < AXIS_COUNT; i++) axisReleased[i] = false;
    }
    for (int i = 0; i < AXIS_COUNT; i++) axisPower((AxisId)i, holdEnabled && !axisReleased[i]);
}
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

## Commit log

2026-05-26 chore: proje iskeletini oluştur
    PlatformIO tabanlı ESP32 kamera slider projesi: step motor kontrolü,
    ayar yönetimi ve web arayüzü temeli.
2026-06-11 feat: PrintLapse entegrasyonu ve WiFi/ağ kurulumu ekle
    - WiFi bağlantı yönetimi (SliderWifi) ve ağ kurulum sayfası eklendi
    - Harici (PrintLapse) kontrol için web arayüzü altyapısı genişletildi
2026-06-15 fix: hareket sırasında ekran donmasını engelle
    [Display.cpp]
2026-06-16 revert: A4988 sürücü ve NEMA 17 yapılandırmasına geri dön
    Sürücü ve motor yapılandırması A4988 + NEMA 17 kombinasyonuna geri alındı.
    [Config.h, SliderControl.cpp]
2026-06-18 feat: step motorları devre dışı bırakma özelliği ekle
    Motorları serbest bırakmak için "disable steppers" kontrolü ve ilgili
    ayarlar eklendi.
2026-06-19 refactor: canlı durum ve kontrolü WebSocket'e taşı
    - :81 portunda WebSocketsServer; durum ~10 Hz ve her komutta istemcilere
    itiliyor. jog/goto/zero/home/auto/motors/estop artık HTTP polling yerine
    düşük gecikme için WebSocket üzerinden
    - Ön yüz WS açıyor ve otomatik yeniden bağlanıyor; HTTP yalnızca sayfa ile
    ayar/wifi yapılandırması için kaldı
    - PrintLapse kalıntıları temizlendi (/api/ping, /api/lock, harici kontrol
    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
2026-07-13 fix: WiFi TX gücünü 8.5 dBm'e sabitle
    ESP32-C3 OLED kartının PCB anteni tam güçte bozulma yapıp AP bağlantılarını
    düşürüyordu; softAP()/begin() sonrası setTxPower ile 8.5 dBm'e çekildi.
    Varsayılan ivmelenme kapatıldı.
    [Config.h, SliderWifi.cpp]
2026-07-13 docs: README ve bağlantı şeması ekle
    Proje tanıtımı, pin haritası tablosu ve Fritzing bağlantı şeması
    (PNG + PDF) docs/ altına eklendi.
2026-08-17 Update README with assembly details and images
    Added assembly information and images to README.
2026-08-17 docs: 3D model STL dosyalarını ve montaj/atıf bilgilerini ekle
    Basılacak parçaların STL dosyaları 3d-models/ altında toplandı:
    slider/ projeye özel parçalar, telefon-tutucu/ ise HeyVye'nin
    Modular Mounting System (CC BY) tasarımından alınan modüller.
    README'ye 3D baskı parçaları bölümü, telefon tutucu için atıf notu
    ve montajın orijinal tasarımcının talimatlarına göre yapılacağı
    bilgisi eklendi.
    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
    [Gt2 holder.STL.stl, Hex Shaft 6.35.stl.stl, Knob for nut long v1.stl.stl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]
2026-08-17 chore: STL dosya adlarındaki çift uzantıları temizle
    "one axis.stl.stl" gibi çift uzantılı ve "Gt2 holder.STL.stl" gibi
    karışık büyük/küçük harfli adlar tek bir .stl uzantısına indirildi.
    Claude-Session: https://claude.ai/code/session_016wMspvHvcynxXBbp11DTXK
    [Gt2 holder.stl, Hex Shaft 6.35.stl, Knob for nut long v1.stl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]
2026-09-11 fix(wifi): AP modunda bloklayan taramayı kaldır, captive portal'ı düzelt
    Wi-Fi kurulum sayfası açılır açılmaz /api/wifi/scan'i üç kez tetikliyordu ve
    handleWifiScan() bloklayan bir tarama yapıyordu (kanal başına 400 ms x ~14
    kanal ~= 5.6 s). Bu süre boyunca telsiz kendi AP kanalından ayrıldığı için
    istemciler association'ı tamamlayamıyor, loop bloke olduğu için de captive
    portal DNS'i ve web sunucusu cevap vermiyordu. Sonuçta telefon "internet yok"
    deyip ağı düşürüyor, portal sayfası da açılmıyordu.
    - Tarama asenkron ve önbellekli hale geldi: Wifi_scanStart() yalnızca başlatır,
    Wifi_loop() sonucu toplar, Wifi_scanJson() son listeyi döner. Kanal ba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
    [Config.h, SliderWifi.cpp, WebInterface.cpp]
2026-09-12 fix(wifi): AP modunda istemcilerin bağlanamamasını çöz
    Üç ayrı sebep AP'yi istemcinin gözünde aralıklı olarak ortadan kaldırıyordu:
    1. AP fallback'e düşerken STA tarafı sessizce kendi başına yeniden bağlanmayı
    deniyordu. Kayıtlı ağ erişilemezse bu denemeler sürekli tekrarlanır ve her
    biri radyoyu AP kanalından saniyelerce koparır - hiçbir istemcinin bir şey
    yapmasına gerek kalmadan. Artık setAutoReconnect(false) + disconnect() ile
    STA pasifleştiriliyor; arayüz yalnızca tarama için ayakta kalıyor.
    2. Kanal süpürmesi AP'yi zamanın %74'ünde, 300 ms'lik bloklar halinde
    kanaldan düşürüyordu. Dwell 300 -> 150 ms, kanal arası boşluk 1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
    [Config.h, SliderWifi.cpp]
2026-09-12 feat(ui): üç adımlı kurulum sihirbazı ve sadeleştirilmiş kontrol ekranı
    Kurulum sihirbazı (her açılışta, üç adım):
    - 1 Home: lineer eksen limit switch'e homing yapar. Motor ters yöne gidiyorsa
    "Wrong way" düğmesi ekseni kalıcı olarak ters çevirip (settings.invertDir)
    homing'i baştan başlatır.
    - 2 Travel: ray uzunluğu ölçümü. Jog ile araba uzak uca sürülür ve o konum
    maxTravelMm olarak kaydedilir. Bu adımdaki jog "free": kayıtlı ray uzunluğunu
    tavan kabul etmez, çünkü ölçülen şey tam olarak odur. Sıfır ucu limit switch
    korumasında kalır. İki jog hızı (hızlı / beşte bir).
    - 3 Pan: rotary eksende switch yok; pan bobinleri serbest b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
    [Config.h, SliderControl.cpp, WebInterface.cpp]
2026-09-12 fix(jog): iki eksene aynı anda basınca motorun takılı kalmasını çöz
    Jog durumu tek bir manualAxis değişkeninde tutuluyordu. Slider basılıyken pan'a
    basılınca bu değişken pan'a dönüyor, ardından slider bırakıldığında
    Slider_manualStop() içindeki "manualAxis == axis" kontrolü tutmadığı için dur
    komutu sessizce yutuluyor ve slider hedefine kadar gitmeye devam ediyordu. Ana
    döngü de yalnızca manualAxis'i izlediğinden, o eksen durunca durum IDLE'a
    dönüyor ve diğer ekseni durdurabilecek kimse kalmıyordu.
    - Firmware: manualAxis yerine eksen başına manualActive[] bayrağı. Her eksenin
    dur komutu kendi başına işliyor; durum yalnızca hiçbir eksen hareke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
    [SliderControl.cpp]
2026-09-13 docs: README'yi sadeleştir ve MIT lisansı ekle
    - Frame 1/2 PDF linkleri kaldırıldı (görseller yeterli)
    - Telefon tutucu atfı üç tekrardan tek paragrafa indirildi
    - İlk kurulum adımları derleme bölümünden çıkarılıp kendi
    "İlk kullanım" bölümüne taşındı, 192.168.4.1 yedeği eklendi
    - LICENSE (MIT) eklendi; telefon tutucu klasörü CC BY istisnası olarak belirtildi
2026-09-13 feat(ui): tüm butonlara basılma efekti ekle
    Her butona basıldığında hafif küçülme (scale .97) ve ton koyulaşması
    (brightness .88) uygulanır. Global kural yalnızca transform + filter
    ayarladığı için jog, set-bar ve segment butonları kendi :active
    renklerini korur; efekt onların üzerine biner.
    - Dolgusuz butonlar (nav sekmeleri, segment, ghost) koyulaşacak zemini
    olmadığından bunun yerine hafif mavi tint alır
    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
2026-09-13 fix(wifi): takılı kalan kanal taraması AP'yi kalıcı olarak düşürüyordu
    scanStep() bir kanal taramasının bitmesini süresiz bekliyordu: scanComplete()
    hiç sonuç döndürmezse g_scanChan hiç temizlenmiyor, sweep hiç bitmiyor ve
    radyo o kanalda park kalıyordu. AP kendi kanalından tamamen kayboluyor,
    istemciler DHCP'yi bile tamamlayamıyor (Windows APIPA'ya düşüp "bağlandı"
    gösteriyor, telefon ağı büsbütün reddediyor) ve durumu düzeltecek hiçbir
    mekanizma yok - yeniden başlatmaya kadar sürüyor.
    - Kanal başına 2 sn timeout: aşılırsa esp_wifi_scan_stop() ile tarama
    iptal edilip radyo AP kanalına geri döndürülüyor, sweep sonraki kanaldan
    devam ediyor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
    [Config.h, SliderWifi.cpp]
2026-09-13 feat(motors): açılışta bobinleri enerjisiz bırak
    12V verilir verilmez iki eksen de tutma torkuna geçiyordu. Açılışta hiçbir
    eksen referanslanmamış olduğu için tutma torkunun bir faydası yok: motorları
    ve sürücüleri boşuna ısıtıyor, beslemeyi yüklüyor ve kullanıcı arabayı elle
    kaydıramıyor.
    Artık Slider_begin() holdEnabled=false ile açılıyor. İlk hareket komutu
    (homing ya da sihirbazın jog'u) applyPowerFor() üzerinden tutmayı geri
    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
2026-09-21 Update README with interface and PrintLapse usage
    Added interface section and usage instructions for PrintLapse.
2026-09-27 fix(wifi): bağlantı kararlılığı, OLED deneme sayacı ve başlangıç/bitiş durumu
    Wi-Fi:
    - Açılışta kayıtlı ağa tek deneme yerine süre bütçesi (15 -> 22.5 sn) içinde
    tekrar tekrar bağlan. Çekirdek başarısız bağlantıyı açılış başına bir kez
    deniyor ve AUTH_FAIL sonrası hiç denemiyordu ("reset'e basınca bağlanıyor").
    - Hotspot modunda kimse bağlı değilken dakikada bir ev ağını tekrar dene.
    - Bağlıyken link 10 sn'den uzun düşerse kendimiz yeniden bağlan.
    - Captive portal DNS'i döngü başına 8 sorgu işlesin; tek sorguda patlama
    halindeki sorgular düşüyor, "ağda oturum aç" bildirimi gelmiyordu.
    - STA modunda TX gücü 15 dBm (AP 8.5 d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
    [Config.h, Display.cpp, SliderWifi.cpp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]
2026-09-28 docs: PrintLapse ile kullanım bölümünü yaz, switch kutusunu ekle
    - Akış görseli (yazıcı -> telefon -> slider), tetikleyici seçenekleri
    (Wi-Fi / switch'e lehimli Bluetooth deklanşör veya kulaklık ses tuşu)
    ve adım adım kullanım.
    - Klipper makroları (TIMELAPSE, TIMELAPSE_ON/OFF, tetikle_kamera), switch
    ile tetikleme örneği ve OrcaSlicer'da Timelapse G-code ayarı.
    - 3d-models/shutter: yazıcı kafasının bastığı switch kutusu (top, bottom).
    [bottom.STL, top.STL]
2026-09-28 docs: montaj videosunu GIF olarak ekle, switch kutusunu kendi tasarımım diye işaretle
    Montaj bölümündeki video, tam çözünürlük ve kare hızında (1920x1080,
    50 fps, 450 kare) GIF'e dönüştürüldü: tüm karelerden tek palet +
    sierra2_4a titreşimi, SSIM 0.9957.
2026-09-28 docs: README'ye PrintLapse Google Play bağlantısını ekle
2026-09-28 docs: switch kutusunun kurulum fotoğraflarını ve yazıcı uyumluluk notunu ekle
2026-11-10 docs: İngilizce README'yi varsayılan yap, Türkçesini README.tr.md'ye taşı
    - README.md artık İngilizce; Türkçe metin README.tr.md'de
    - İki dosyanın başına dil seçici eklendi
    - Tetikleyici seçeneklerine Görsel tetikleyici (Visual trigger) eklendi
